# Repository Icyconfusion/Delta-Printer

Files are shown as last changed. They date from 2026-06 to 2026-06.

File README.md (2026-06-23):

# Delta Printer
An STM32 based delta style 3D printer running Marlin firmware. The printer features a custom PCB motherboard, LCD, and 220mm diameter x roughly 200mm build volume. I designed this project to expand on my understanding of 3D printer hardware and mechanics through non-standard motion.



**Note to reviewer:** My JLCPCB/MC screenshot is inclusive of tax and cheapest shipping option, it went into my "orders" tab despite not being paid for, but that is the total price, and the checkout page. Thank you:)

## Assembly
The key assembly ofthe printer is a triangular prism made of 2020 T slot aluminium profiles. Using 3d printed brackets, shorter T slots of lengths 340mm for the top and 290 for the bottom are arranged into triangles. 500mm T slot join these triangles. Two profiles are used for each tower to increase stiffness. The bottom bracket extends the height of the printer without needing extra T slot. Brackets are mounted using T nuts.




400mm MGN12H linear rails are mounted to the inside profile of each tower using M3x8 screws.



To mount the NEMA17 stepper motors, the motors are screwed into the mount bracket, which attaches to the inside of the two bottom triangles.





Bottom covers are added and the PCB is placed in the groove in the centre.




Idle pulleys are mounted to the top bracket with an M5 screw. The carriages are assembled with the ball joints screwed onto the carriage. M3 screws are threaded into the heat inserts and the GT2 belt is mounted. The carbon tube has an M3 stud glue into each end, which is threaded into the ball joint on each end.






### Effector Assembly
To assemble the effector, first mount the NEMA 17 stepper and filament gear.





Then mount the CR6-SE hotend into the heat inserts.



4010 fans mount on the back and side where they are ducted to the nozzle/part.




The extruder arm provides tension to the filament gear to ensure accurate and reliable extrusion of filament. The arm is spring loaded to push an 11x5x5 bearing, squeezing the filament against the drive gear. The arm pivots around the top left M3 NEMA 17 mounting screw. An M5 screw above this is threaded into the effector knob, and a spring in this spot provides tension. Finally, the ball joints are attached, and can be connected to the arms on the carriages.






To start closing the base compartment and installing the bed, the LCD must be installed. The LCD is screwed through the back into heat inserts in the LCD module printed part. This module is then mounted onto LCD base covers using heat inserts. This is then mounted onto the base using T nuts.









Base covers are mounted onto one of the other sides.



The third side holds the PSU. The PSU is held in its compartment, which is mounted to the frame in place. A base cover is mounted next to it. There is a hole in the base cover next to it for power cables to run from to PSU to the wall outlet.







Now the bed can be installed. To do this, printed bed supports are installed on the base. The bed then screws into these. If needed, depending on exact specifications of the bed, the holes to mount the bed can be made larger by printing or drilling.




To mount limit switches, the switches are screwed into heat inserts in the bracket, then mounted to the bottom of the towers. After this the printer is assembled.




## Electronics
The printer features a 2 layer PCB motherboard I designed around an STM32F407VGT6. TMC2209 drivers are used to control stepper motors, and subsequently motion. The board utilises mostly SMD components to minimise space and layer requirements. Power is brought onto the board using 7.62mm pitch screw terminals, which connect to the 24V 600w PSU. A buck converter and linear regulator convert this down to 5V and 3.3V logic levels. 5V is used only for the buck converter and the EXP1 header for the LCD. The LCD used it a BTT Mini 12864 V2.0, which interfaces with the PCB via EXP1 and EXP2 headers. The LCD also has an encoder, button and SD card reader. The heaters (hotend and bed if required in future) are controlled through TO-252-3 AOD4184 MOSFETs. Lower power mosfets, SOT-23 AO3400 MOSFETs, are used to control the 24V fans. There is a USB-C receptacle for firmware flashing, and an SWD header if needed. Most resistors and capacitors are size 0805, though there are exceptionswhere required. Because I am using the STM32, no external flash is required, as it is onboard.



Driver hierarchical sheet:



MOSFET hierarchical sheet:






Power:



EXP1 and EXP2:



The PCB is organised with drivers up the top. Power on the left edge, with the buck converter, regulator, power input terminal and fuse. MOSFETs are on the bottom, heaters on the right hand side. On the right edge, there is the USB-C receptacle, thermistors, endstops and LCD headers. The STM32 is situated in the center.





## Firmware
The firmware used is Marlin firmware. The firmware has been configured to match a delta printer with delta kinematics. Additionally, it has been configured for my custom motherboard by creating a unique pin mapping for the printer. The config and pin map files are in the firmware folder of the repo, along with the complete marlin .zip build folder.

## BOM
### Printed Parts

|Part| Quantity| Image|
|---|---|---|
|Bottom bracket | 3 |  |
|Top bracket | 3 |  |
|Bottom cover | 3 |  |
|Bed support | 3 |  |
|Motor mount | 3 |  |
|Carriage | 3 |  |
|PSU compartment | 3 |  |
|Base cover LCD | 2 |  |
|Base cover | 2 |  |
|Base cover PSU | 1 |  |
|LCD front cover | 1 |  |
|Extruder | 1 |  |
|Drive arm | 1 |  |
|Limit switch bracket | 3 |  |

### Parts already owned
| Part | Quantity | Description |
|--|--|--|
|T slot | 6 | 500mm 2020 T slot profiles |
|Linear rail | 3 | MGN12H 400mm linear rail and carriage |
|Motor | 4 | NEMA 17 stepper motor |
| Hotend | 1 | CR6 SE hotend |
| Fan | 2 | 4010 24v blower fan |
| GT2 bearing | 3 | 5mm bore gt2 idler bearing |
| GT2 gear | 3 | GT2 20T gear |
|LCD | 1 | BTT mini 12864 V2.0 LCD |
| Limit switch | 3 | Standard limit switch |
| T nut | - | M5 and M3 T nuts |
| PSU | 1 | 24V 600w PSU |

### Purchased parts
|Product |Quantity|Description |Total cost (USD)|Supplier  |Link |
|---|---|---|---|---|---|
|100nF Capacitors |26 |100nF 0805 ceramic capacitors for PCB |2.31 |Aliexpress|https://www.aliexpress.com/item/1005011894977575.html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 |
|100uF - Low ESR Cap|6 |50V 100uF Low ESR caps in 6.3x7.7 package. Used for Vm on TMC2209 |3.69 |Aliexpress|https://www.aliexpress.com/item/1005006846973435.html |
|2.2uF cap |6 |0805 2.2uF 50V ceramic capacitors |2.2 |Aliexpress|https://www.aliexpress.com/item/1005007293718666.html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 |
|22nF cap |4 |0805 22nF 50V ca- |2.2 |Aliexpress|https://www.aliexpress.com/item/1005011894977575.html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 |
|1uF cap |4 |0805 1uF 50V capacitor |2.04 |Aliexpress|https://www.aliexpress.com/item/1005007293718666.html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 |
|18pF cap |2 |0805 18pF cap for crystal |2.52 |Aliexpress|https://www.aliexpress.com/item/1005002958706092.html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 |
|22uF cap |4 |0805 22uF 50V capacitor |2.86 |Aliexpress|https://www.aliexpress.com/item/1005007293718666.html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 |
|10uF cap |6 |0805 10uF cap |2.54 |Aliexpress|https://www.aliexpress.com/item/1005007293718666.html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 |
|220pF cap |1 |0805 220pF 50V cap |4.04 |Aliexpress|https://www.aliexpress.com/item/1005011884524334.html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 |
|SS34 diode |1 |SS34 SMA Schottky diode |2.89 |Aliexpress|https://www.aliexpress.com/item/1005003929814084.html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 |
|Ferrite bead |1 |0805 600R 100mhz ferrite bead |3.93 |Aliexpress|https://www.aliexpress.com/item/1005003127666910.html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 |
|IDC header |2 |2x5 pin 2.54mm IDC header for EXP1/2 |4.77 |Aliexpress|https://www.aliexpress.com/item/32658384492.html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 |
|JST-XH header |7 |JST-XH 2.54mm header for conencting heaters and fans |1.83 |Aliexpress|https://www.aliexpress.com/item/1005004985397880.html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 |
|10uH inductor |1 |6x6x3 10uH inductor |3.5 |Aliexpress|https://www.aliexpress.com/item/1005006817003873.html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 |
|MOSFET |2 |TO252-3 AOD4184 SMD MOSFET for heaters |3.7 |Aliexpress|https://www.aliexpress.com/item/1005006044488568.html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 |
|Fan MOSFET |3 |SOT-23 AO3400 SMD MOSFET |1.87 |Aliexpress|https://www.aliexpress.com/item/1005006286601118.html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 |
|Resistor 0.5W |8 |1206 0.5W 0.15 ohm sense resistor for TMC 2209 |1.62 |Aliexpress|https://www.aliexpress.com/item/1005005905538731.html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 |
|1K resistor |5 |0805 1k ohm resistor |2.48 |Aliexpress|https://www.aliexpress.com/item/32936483115.html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 |
|10k resistor |12 |0805 10k resistor |2.53 |Aliexpress|https://www.aliexpress.com/item/32936483115.html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 |
|100 resistor |6 |100 ohm 0805 resistor |2.44 |Aliexpress|https://www.aliexpress.com/item/32936483115.html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 |
|5.1K resistor |2 |0805 5.1k resistor |2.48 |Aliexpress|https://www.aliexpress.com/item/32936483115.html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 |
|33 resistor |2 |0805 33 ohm resistor |2.44 |Aliexpress|https://www.aliexpress.com/item/32936483115.html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 |
|52.3K resistor |1 |0805 52.3k resistor |1.8 |Aliexpress|https://www.aliexpress.com/item/1005005184354247.html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 |
|100k resistor |1 |0805 100k resistor |3.04 |Aliexpress|https://www.aliexpress.com/item/1005007183002569.html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 |
|24.9K resistor |1 |0805 24.9k resistor |1.72 |Aliexpress|https://www.aliexpress.com/item/1005005184354288.html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 |
|68.1K resistor |1 |0805 68.1k resistor |1.72 |Aliexpress|https://www.aliexpress.com/item/1005005187548543.html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 |
|22 resistor |2 |0805 22 ohm resistor |2.59 |Aliexpress|https://www.aliexpress.com/item/32936483115.html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 |
|Pushbutton |1 |TS-1088-AR02016 pushbutton |1.09 |Aliexpress|https://www.aliexpress.com/item/1005011940516004.html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 |
|STM32 |1 |STM32F407VGT6 MCU |4.58 |Aliexpress|https://www.aliexpress.com/item/1005006367005179.html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 |
|TMC2209-LA |4 |TMC 2209 stepper driver |7.12 |Aliexpress|https://www.aliexpress.com/item/1005009186342077.html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 |
|MP1584-EN |1 |Buck converter for 24V to 5V |3.23 |Aliexpress|https://www.aliexpress.com/item/1005007296268441.html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 |
|AP-2112K-3.3 |1 |Linear regulator for 5V to 3.3V |2.43 |Aliexpress|https://www.aliexpress.com/item/1005009023441155.html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 |
|Crystal |1 |8mhz 3225 SMD crystal, 4 pad |3 |Aliexpress|https://www.aliexpress.com/item/1005005834614422.html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 |
|Bed |1 |220mm diameter kossel delta 3d print bed |18.8 |Aliexpress|https://www.aliexpress.com/item/33042838050.html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 |
|Carbon tube |2 |500mm lengths of 8x6 carbon fibre tube. Comes in packs of two, I will need two packs, and cut each rod into two 230mm lengths|14 |Aliexpress|https://www.aliexpress.com/item/1005006133534969.html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 |
|Ball joints |12 |M3 26mm ball joints for the arms |11 |Aliexpress|https://www.aliexpress.com/item/1005006781375729.html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 |
|GT2 belt |1 |5M GT2 6mm belt for moving the carriages |4.3 |Aliexpress|https://www.aliexpress.com/item/1005008378063451.html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 |
|Filament drive gear|1 |Filament drive gear to extrude filament |2.18 |Aliexpress|https://www.aliexpress.com/item/32296703817.html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 |
|Bearing |1 |11x5x5 bearing for idler arm |0.11 |JLCMC |https://jlcmc.com/product/b/C15/BR8364/deep-groove-ball-bearing-double-side-with-dust-cover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 |
|M5x16 |2 |SCM435 screw for assembly |0.04 |JLCMC |https://jlcmc.com/product/s/E02/EDLA/din-912-gb-t-70.1-standard-socket-head-cap-screws-full---half-thread |
|M5x22 |1 |SCM435 screw for assembly |0.02 |JLCMC |https://jlcmc.com/product/s/E02/EDLA/din-912-gb-t-70.1-standard-socket-head-cap-screws-full---half-thread |
|M5x10 |75 |SCM435 screw for assembly |1.18 |JLCMC |https://jlcmc.com/product/s/E02/EDLA/din-912-gb-t-70.1-standard-socket-head-cap-screws-full---half-thread |
|M3x8 |48 |SCM435 screw for assembly |0.56 |JLCMC |https://jlcmc.com/product/s/E02/EDLA/din-912-gb-t-70.1-standard-socket-head-cap-screws-full---half-thread |
|M3x10 |31 |SCM435 screw for assembly |0.25 |JLCMC |https://jlcmc.com/product/s/E02/EDLA/din-912-gb-t-70.1-standard-socket-head-cap-screws-full---half-thread |
|340mm T slot |3 |340mm 2020 T slot |2.63 |JLCMC |https://jlcmc.com/product/s/T01/TXCJ/extruded-aluminum-t-slot-20-series(eu) |
|290mm T slot |6 |290mm 2020 T slot for the base triangles |4.8 |JLCMC |https://jlcmc.com/product/s/T01/TXCJ/extruded-aluminum-t-slot-20-series(eu) |
|M3 heat insert |4 |M3 OD4 L5-6mm |2.53 |Aliexpress|https://www.aliexpress.com/item/1005008897571758.html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|
|M2 heat insert |6 |M2 OD3.2 L6 |2.42 |Aliexpress|https://www.aliexpress.com/item/1005008666672949.html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 |
|M5 heat insert |3 |M5 OD7.1 L6 |2.61 |Aliexpress|https://www.aliexpress.com/item/1005008666672949.html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 |
|M2.5 Heat insert |8 |M2.5 OD3.5 L6 |2.47 |Aliexpress|https://www.aliexpress.com/item/1005008897571758.html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|
|PCB |1 |PCB |8.89 |JLCPCB |https://jlcmc.com/product/s/E02/EDLA/din-912-gb-t-70.1-standard-socket-head-cap-screws-full---half-thread |

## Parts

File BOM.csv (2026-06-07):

Product | Quantity | Description | Total cost (USD) | Supplier | Link
100nF Capacitors | 26 | 100nF 0805 ceramic capacitors for PCB | 2.31 | Aliexpress | https://www.aliexpress.com/item/1005011894977575.html?curPageLogUid=lO0BHaX0NqCM
100uF - Low ESR Cap | 6 | 50V 100uF Low ESR caps in 6.3x7.7 package. Used for Vm on TMC2209 | 3.69 | Aliexpress | https://www.aliexpress.com/item/1005006846973435.html
2.2uF cap | 6 | 0805 2.2uF 50V ceramic capacitors | 2.2 | Aliexpress | https://www.aliexpress.com/item/1005007293718666.html?curPageLogUid=OS4dkcks5GAl
22nF cap | 4 | 0805 22nF 50V ca- | 2.2 | Aliexpress | https://www.aliexpress.com/item/1005011894977575.html?curPageLogUid=lO0BHaX0NqCM
1uF cap | 4 | 0805 1uF 50V capacitor | 2.04 | Aliexpress | https://www.aliexpress.com/item/1005007293718666.html?curPageLogUid=OS4dkcks5GAl
18pF cap | 2 | 0805 18pF cap for crystal | 2.52 | Aliexpress | https://www.aliexpress.com/item/1005002958706092.html?curPageLogUid=HO0lalvIulA4
22uF cap | 4 | 0805 22uF 50V capacitor | 2.86 | Aliexpress | https://www.aliexpress.com/item/1005007293718666.html?curPageLogUid=OS4dkcks5GAl
10uF cap | 6 | 0805 10uF cap | 2.54 | Aliexpress | https://www.aliexpress.com/item/1005007293718666.html?curPageLogUid=OS4dkcks5GAl
220pF cap | 1 | 0805 220pF 50V cap | 4.04 | Aliexpress | https://www.aliexpress.com/item/1005011884524334.html?curPageLogUid=1xTiDLuHV5Su
SS34 diode | 1 | SS34 SMA Schottky diode | 2.89 | Aliexpress | https://www.aliexpress.com/item/1005003929814084.html?curPageLogUid=NnPur3r1YfyF
Ferrite bead | 1 | 0805 600R 100mhz ferrite bead | 3.93 | Aliexpress | https://www.aliexpress.com/item/1005003127666910.html?curPageLogUid=ES5AkXMpY2mV
IDC header | 2 | 2x5 pin 2.54mm IDC header for EXP1/2 | 4.77 | Aliexpress | https://www.aliexpress.com/item/32658384492.html?curPageLogUid=g4IB6NhYXd4C
JST-XH header | 7 | JST-XH 2.54mm header for conencting heaters and fans | 1.83 | Aliexpress | https://www.aliexpress.com/item/1005004985397880.html?curPageLogUid=7n7ud5jLy3vZ
10uH inductor | 1 | 6x6x3 10uH inductor | 3.5 | Aliexpress | https://www.aliexpress.com/item/1005006817003873.html?curPageLogUid=Uw0smIdCVuNn
MOSFET | 2 | TO252-3 AOD4184 SMD MOSFET for heaters | 3.7 | Aliexpress | https://www.aliexpress.com/item/1005006044488568.html?curPageLogUid=S5OfV9YlN4WJ
Fan MOSFET | 3 | SOT-23 AO3400 SMD MOSFET | 1.87 | Aliexpress | https://www.aliexpress.com/item/1005006286601118.html?curPageLogUid=dHrfVQrllnN6
Resistor 0.5W | 8 | 1206 0.5W 0.15 ohm sense resistor for TMC 2209 | 1.62 | Aliexpress | https://www.aliexpress.com/item/1005005905538731.html?curPageLogUid=Pfo42AofQ8rk
1K resistor | 5 | 0805 1k ohm resistor | 2.48 | Aliexpress | https://www.aliexpress.com/item/32936483115.html?curPageLogUid=dNfs5t7vpWyj
10k resistor | 12 | 0805 10k resistor | 2.53 | Aliexpress | https://www.aliexpress.com/item/32936483115.html?curPageLogUid=dNfs5t7vpWyj
100 resistor | 6 | 100 ohm 0805 resistor | 2.44 | Aliexpress | https://www.aliexpress.com/item/32936483115.html?curPageLogUid=dNfs5t7vpWyj
5.1K resistor | 2 | 0805 5.1k resistor | 2.48 | Aliexpress | https://www.aliexpress.com/item/32936483115.html?curPageLogUid=dNfs5t7vpWyj
33 resistor | 2 | 0805 33 ohm resistor | 2.44 | Aliexpress | https://www.aliexpress.com/item/32936483115.html?curPageLogUid=dNfs5t7vpWyj
52.3K resistor | 1 | 0805 52.3k resistor | 1.8 | Aliexpress | https://www.aliexpress.com/item/1005005184354247.html?curPageLogUid=rQRCWdSXORAa
100k resistor | 1 | 0805 100k resistor | 3.04 | Aliexpress | https://www.aliexpress.com/item/1005007183002569.html?curPageLogUid=CMCONd03B1Mp
24.9K resistor | 1 | 0805 24.9k resistor | 1.72 | Aliexpress | https://www.aliexpress.com/item/1005005184354288.html?curPageLogUid=G58tsGOWqItU
68.1K resistor | 1 | 0805 68.1k resistor | 1.72 | Aliexpress | https://www.aliexpress.com/item/1005005187548543.html?curPageLogUid=MXuPuWllAnmZ
22 resistor | 2 | 0805 22 ohm resistor | 2.59 | Aliexpress | https://www.aliexpress.com/item/32936483115.html?curPageLogUid=dNfs5t7vpWyj
Pushbutton | 1 | TS-1088-AR02016 pushbutton | 1.09 | Aliexpress | https://www.aliexpress.com/item/1005011940516004.html?curPageLogUid=CfBxlh486V12
STM32 | 1 | STM32F407VGT6 MCU | 4.58 | Aliexpress | https://www.aliexpress.com/item/1005006367005179.html?curPageLogUid=dqBBw4AoHYAD
TMC2209-LA | 4 | TMC 2209 stepper driver | 7.12 | Aliexpress | https://www.aliexpress.com/item/1005009186342077.html?curPageLogUid=HlIqvvGecP1u
MP1584-EN | 1 | Buck converter for 24V to 5V | 3.23 | Aliexpress | https://www.aliexpress.com/item/1005007296268441.html?curPageLogUid=A34AWEWBjMRx
AP-2112K-3.3 | 1 | Linear regulator for 5V to 3.3V | 2.43 | Aliexpress | https://www.aliexpress.com/item/1005009023441155.html?curPageLogUid=zwSUqLx0jcxh
Crystal | 1 | 8mhz 3225 SMD crystal, 4 pad | 3 | Aliexpress | https://www.aliexpress.com/item/1005005834614422.html?curPageLogUid=t2KRH5g72Zws
Bed | 1 | 220mm diameter kossel delta 3d print bed | 18.8 | Aliexpress | https://www.aliexpress.com/item/33042838050.html?mp=1
Carbon tube | 2 | 500mm lengths of 8x6 carbon fibre tube. Comes in packs of two, I will need two packs, and cut each rod into two 230mm lengths | 14 | Aliexpress | https://www.aliexpress.com/item/1005006133534969.html?mp=1
Ball joints | 12 | M3 26mm ball joints for the arms | 11 | Aliexpress | https://www.aliexpress.com/item/1005006781375729.html?curPageLogUid=FTtu6kDYbUIQ
GT2 belt | 1 | 5M GT2 6mm belt for moving the carriages | 4.3 | Aliexpress | https://www.aliexpress.com/item/1005008378063451.html?curPageLogUid=wyaNDkXzWcC4
Filament drive gear | 1 | Filament drive gear to extrude filament | 2.18 | Aliexpress | https://www.aliexpress.com/item/32296703817.html?curPageLogUid=DQ9u4zyL0oho
Bearing | 1 | 11x5x5 bearing for idler arm | 0.11 | JLCMC | https://jlcmc.com/product/b/C15/BR8364/deep-groove-ball-bearing-double-side-with-dust-cover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
M5x16 | 2 | SCM435 screw for assembly | 0.04 | JLCMC | https://jlcmc.com/product/s/E02/EDLA/din-912-gb-t-70.1-standard-socket-head-cap-screws-full---half-thread
M5x22 | 1 | SCM435 screw for assembly | 0.02 | JLCMC | https://jlcmc.com/product/s/E02/EDLA/din-912-gb-t-70.1-standard-socket-head-cap-screws-full---half-thread
M5x10 | 75 | SCM435 screw for assembly | 1.18 | JLCMC | https://jlcmc.com/product/s/E02/EDLA/din-912-gb-t-70.1-standard-socket-head-cap-screws-full---half-thread
M3x8 | 48 | SCM435 screw for assembly | 0.56 | JLCMC | https://jlcmc.com/product/s/E02/EDLA/din-912-gb-t-70.1-standard-socket-head-cap-screws-full---half-thread
M3x10 | 31 | SCM435 screw for assembly | 0.25 | JLCMC | https://jlcmc.com/product/s/E02/EDLA/din-912-gb-t-70.1-standard-socket-head-cap-screws-full---half-thread
340mm T slot | 3 | 340mm 2020 T slot | 2.63 | JLCMC | https://jlcmc.com/product/s/T01/TXCJ/extruded-aluminum-t-slot-20-series(eu)
290mm T slot | 6 | 290mm 2020 T slot for the base triangles | 4.8 | JLCMC | https://jlcmc.com/product/s/T01/TXCJ/extruded-aluminum-t-slot-20-series(eu)
M3 heat insert | 4 | M3 OD4 L5-6mm | 2.53 | Aliexpress | https://www.aliexpress.com/item/1005008897571758.html?curPageLogUid=nP77GEie3UaZ
M2 heat insert | 6 | M2 OD3.2 L6 | 2.42 | Aliexpress | https://www.aliexpress.com/item/1005008666672949.html?curPageLogUid=lO13mEhcc5fv
M5 heat insert | 3 | M5 OD7.1 L6 | 2.61 | Aliexpress | https://www.aliexpress.com/item/1005008666672949.html?curPageLogUid=lO13mEhcc5fv
M2.5 Heat insert | 8 | M2.5 OD3.5 L6 | 2.47 | Aliexpress | https://www.aliexpress.com/item/1005008897571758.html?curPageLogUid=nP77GEie3UaZ
PCB | 1 | PCB | 8.89 | JLCPCB | https://jlcmc.com/product/s/E02/EDLA/din-912-gb-t-70.1-standard-socket-head-cap-screws-full---half-thread

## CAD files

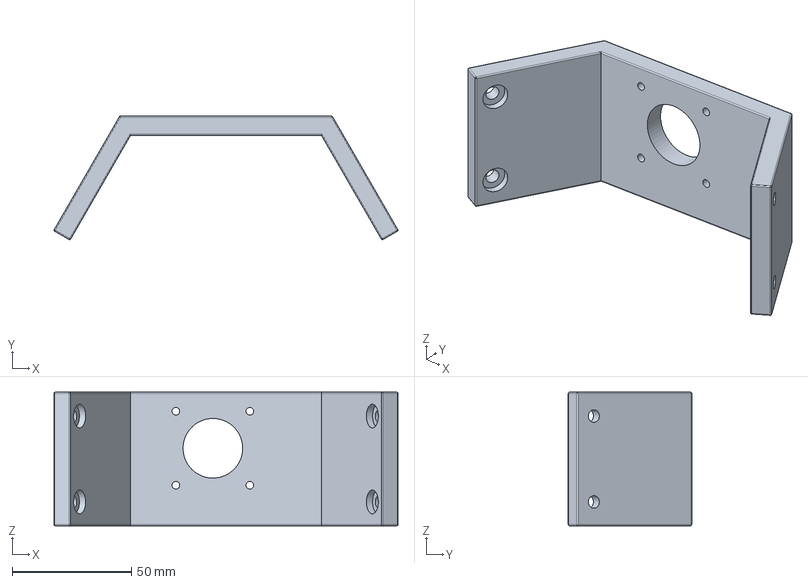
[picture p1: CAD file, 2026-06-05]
CAD/New motor mount.step
144.2 x 51.8 x 56.0 mm

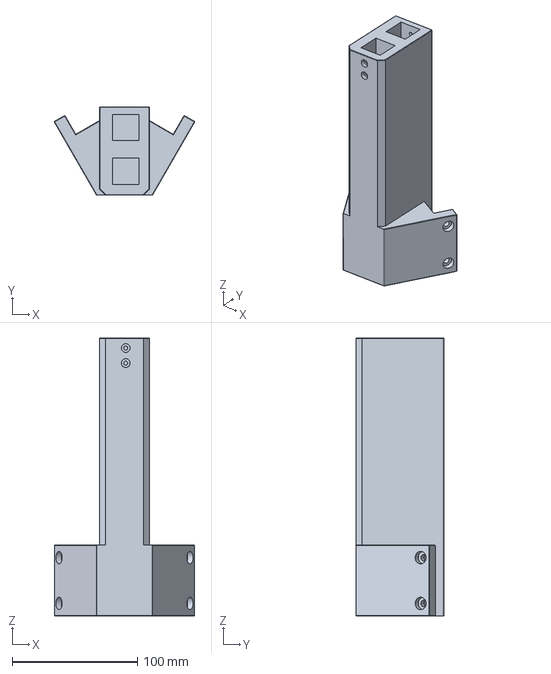
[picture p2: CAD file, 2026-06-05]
CAD/Bottom bracket.step
112.0 x 70.5 x 221.5 mm

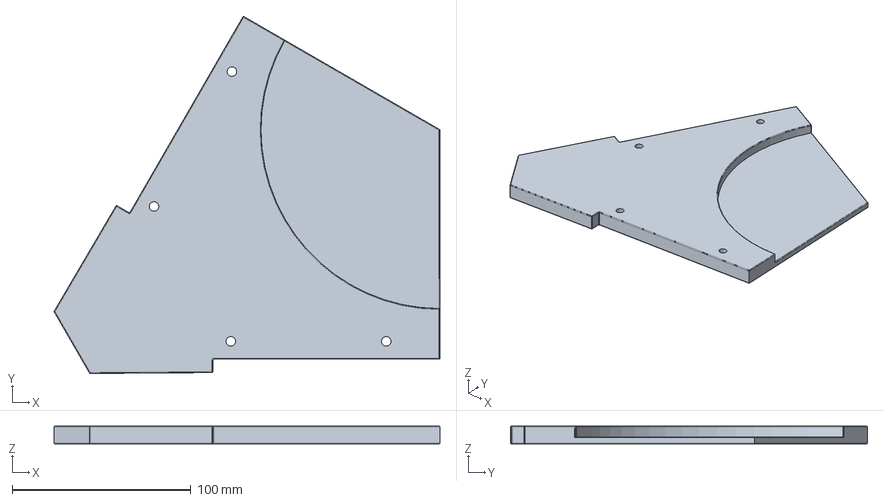
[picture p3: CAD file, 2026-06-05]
CAD/Bottom cover.step
215.7 x 199.6 x 10.0 mm

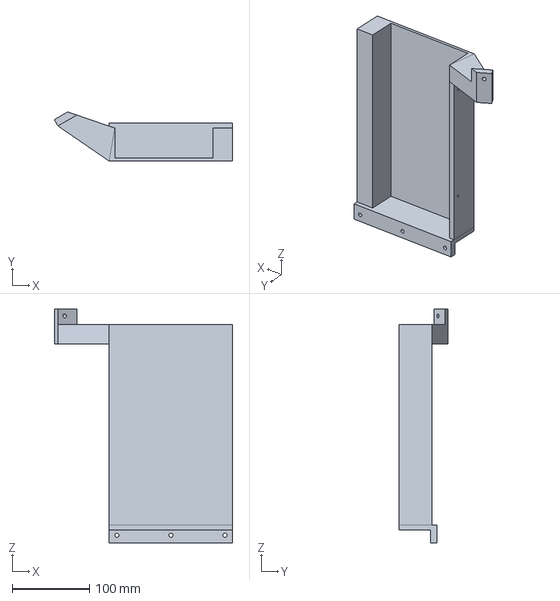
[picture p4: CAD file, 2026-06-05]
CAD/PSU Compartment.step
231.0 x 63.7 x 302.9 mm

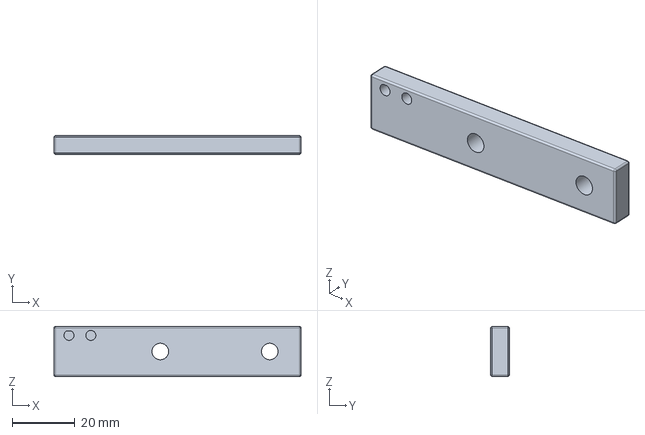
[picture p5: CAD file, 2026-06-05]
CAD/Limit switch bracket.step
79.0 x 6.00 x 16.0 mm

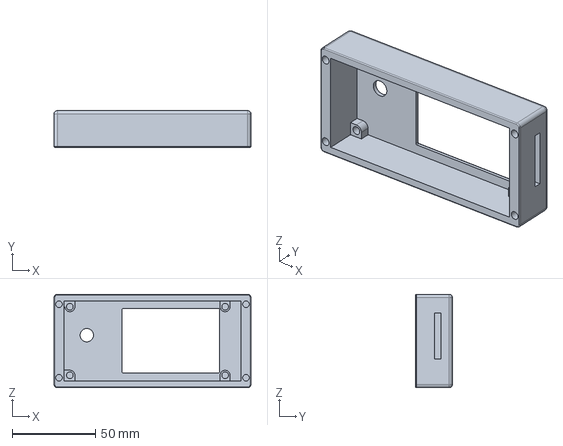
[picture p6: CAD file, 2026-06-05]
CAD/LCD front cover.step
118.0 x 22.0 x 56.0 mm

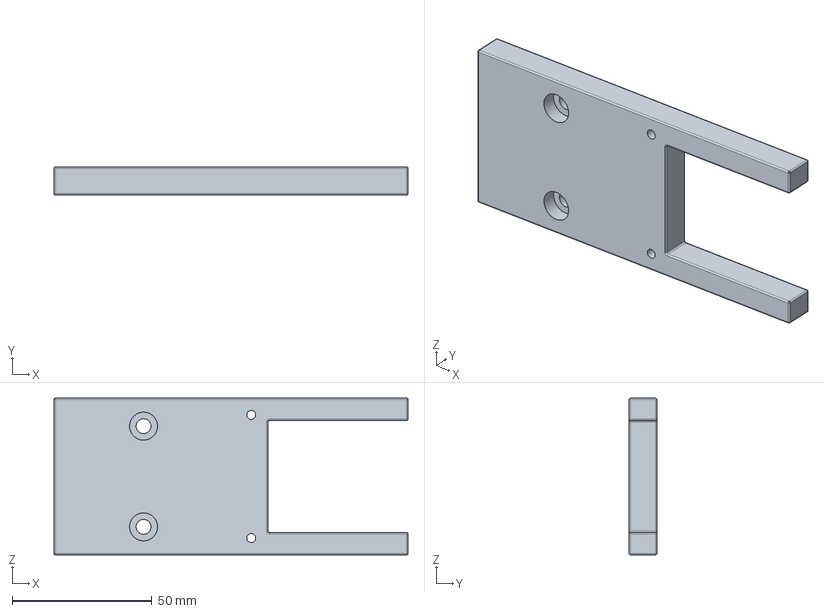
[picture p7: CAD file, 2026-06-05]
CAD/Base cover LCD_.step
126.5 x 10.0 x 56.0 mm

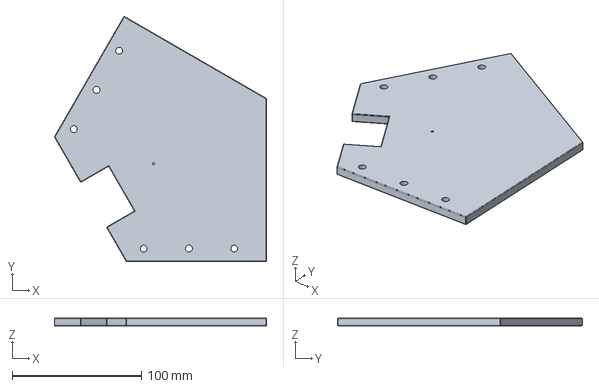
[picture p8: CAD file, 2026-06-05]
CAD/Bed support.step
164.0 x 189.5 x 6.00 mm

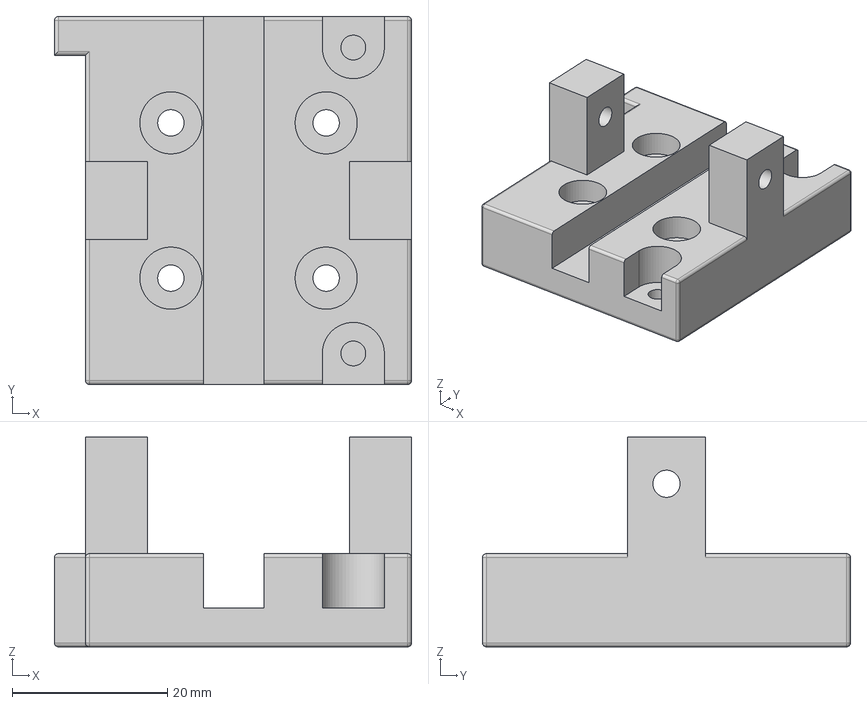
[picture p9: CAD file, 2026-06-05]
CAD/Carriage.step
46.0 x 47.4 x 27.0 mm

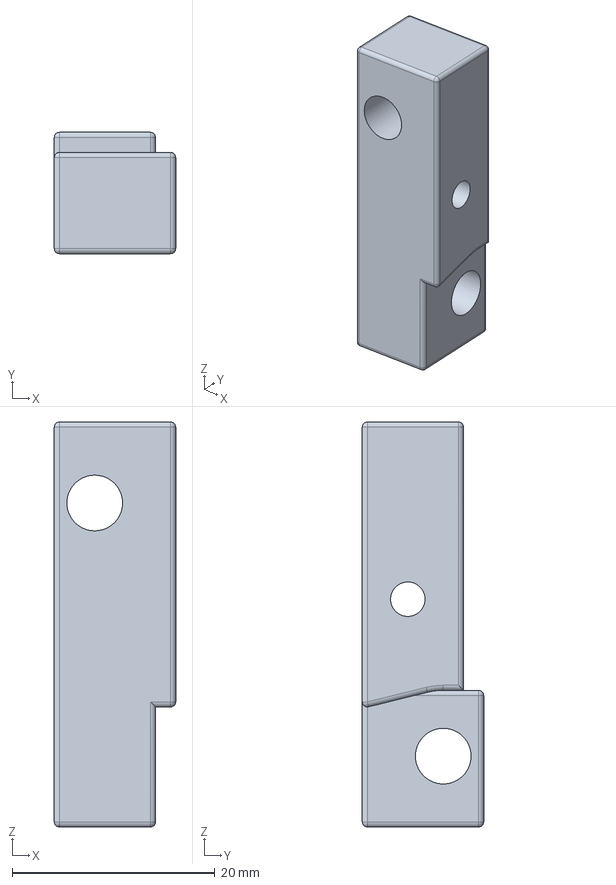
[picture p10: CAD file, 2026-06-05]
CAD/Drive arm.step
12.0 x 12.0 x 40.0 mm

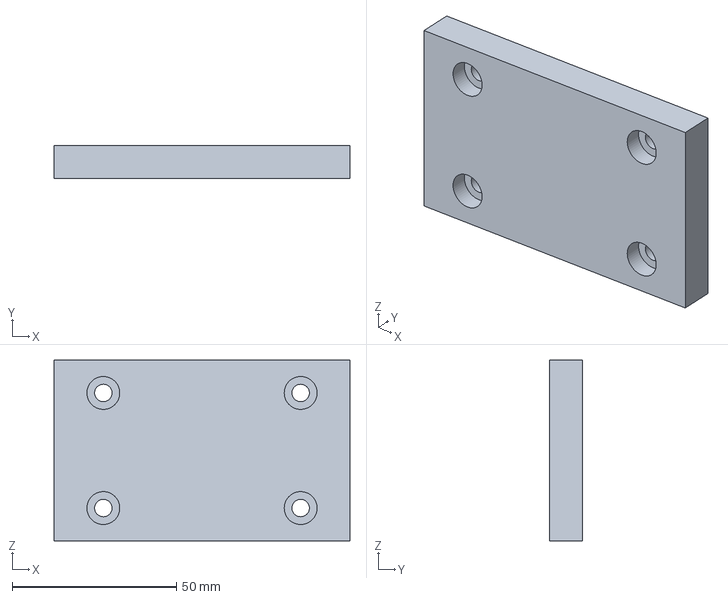
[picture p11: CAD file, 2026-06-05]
CAD/PSU base cover.step
90.0 x 10.0 x 55.0 mm

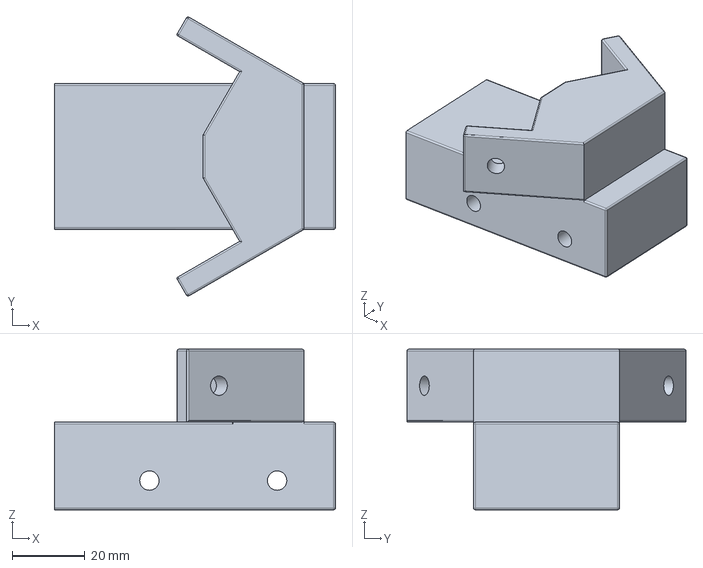
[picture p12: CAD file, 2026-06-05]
CAD/Top bracket.step
77.0 x 76.5 x 44.0 mm

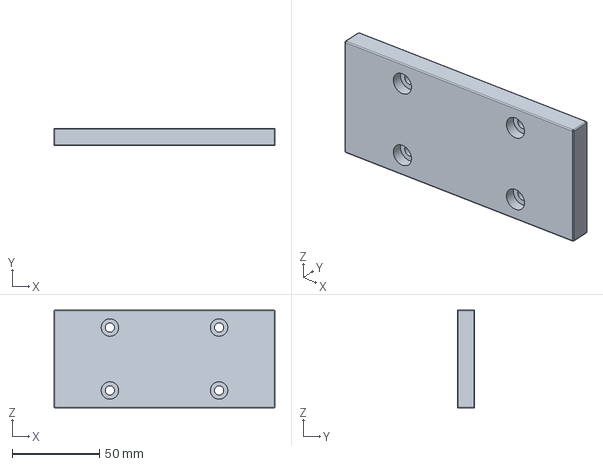
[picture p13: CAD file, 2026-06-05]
CAD/Base cover.step
126.5 x 10.0 x 56.0 mm

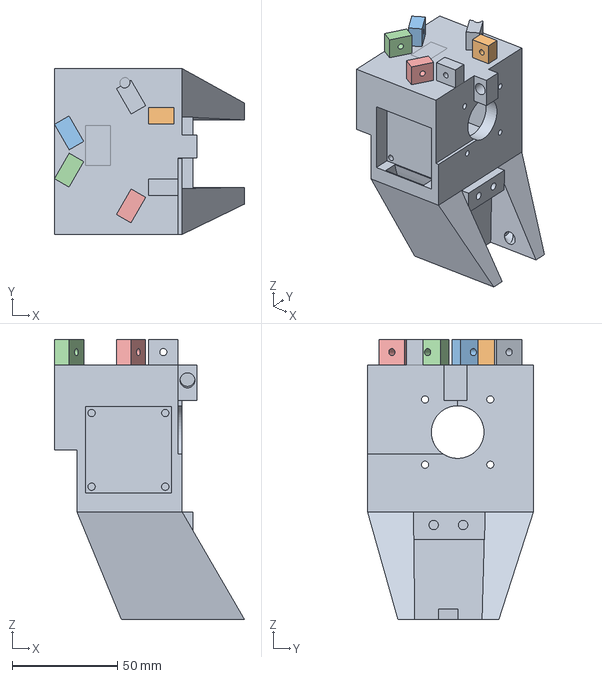
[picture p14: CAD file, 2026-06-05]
CAD/Extruder.step
90.3 x 78.8 x 133.1 mm

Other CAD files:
Assembly/Assembly.stp

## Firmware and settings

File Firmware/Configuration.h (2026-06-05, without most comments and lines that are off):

#pragma once
#define CONFIGURATION_H_VERSION 02010206
#define STRING_CONFIG_H_AUTHOR "(none, default config)" // Who made the changes.
#define SHOW_BOOTSCREEN
  #define MOTHERBOARD BOARD_DELTA
#define SERIAL_PORT 0
#define BAUDRATE 250000
#define X_DRIVER_TYPE  TMC2209
#define Y_DRIVER_TYPE  TMC2209
#define Z_DRIVER_TYPE  TMC2209
#define E0_DRIVER_TYPE TMC2209
#define EXTRUDERS 1
#define DEFAULT_NOMINAL_FILAMENT_DIA 1.75
#define TEMP_SENSOR_0 1
#define TEMP_SENSOR_1 0
#define TEMP_SENSOR_2 0
#define TEMP_SENSOR_3 0
#define TEMP_SENSOR_4 0
#define TEMP_SENSOR_5 0
#define TEMP_SENSOR_6 0
#define TEMP_SENSOR_7 0
#define TEMP_SENSOR_BED 1
#define TEMP_SENSOR_PROBE 0
#define TEMP_SENSOR_CHAMBER 0
#define TEMP_SENSOR_COOLER 0
#define TEMP_SENSOR_BOARD 0
#define TEMP_SENSOR_REDUNDANT 0
#define DUMMY_THERMISTOR_998_VALUE  25
#define DUMMY_THERMISTOR_999_VALUE 100
#if TEMP_SENSOR_IS_MAX_TC(0)
  #define MAX31865_SENSOR_OHMS_0      100 // (Ω) Typically 100 or 1000 (PT100 or PT1000)
  #define MAX31865_CALIBRATION_OHMS_0 430 // (Ω) Typically 430 for Adafruit PT100; 4300 for Adafruit PT1000
#endif
#if TEMP_SENSOR_IS_MAX_TC(1)
  #define MAX31865_SENSOR_OHMS_1      100
  #define MAX31865_CALIBRATION_OHMS_1 430
#endif
#if TEMP_SENSOR_IS_MAX_TC(2)
  #define MAX31865_SENSOR_OHMS_2      100
  #define MAX31865_CALIBRATION_OHMS_2 430
#endif
#if HAS_E_TEMP_SENSOR
  #define TEMP_RESIDENCY_TIME         10  // (seconds) Time to wait for hotend to "settle" in M109
  #define TEMP_WINDOW                  1  // (°C) Temperature proximity for the "temperature reached" timer
  #define TEMP_HYSTERESIS              3  // (°C) Temperature proximity considered "close enough" to the target
#endif
#if TEMP_SENSOR_BED
  #define TEMP_BED_RESIDENCY_TIME     10  // (seconds) Time to wait for bed to "settle" in M190
  #define TEMP_BED_WINDOW              1  // (°C) Temperature proximity for the "temperature reached" timer
  #define TEMP_BED_HYSTERESIS          3  // (°C) Temperature proximity considered "close enough" to the target
#endif
#if TEMP_SENSOR_CHAMBER
  #define TEMP_CHAMBER_RESIDENCY_TIME 10  // (seconds) Time to wait for chamber to "settle" in M191
  #define TEMP_CHAMBER_WINDOW          1  // (°C) Temperature proximity for the "temperature reached" timer
  #define TEMP_CHAMBER_HYSTERESIS      3  // (°C) Temperature proximity considered "close enough" to the target
#endif
#if TEMP_SENSOR_REDUNDANT
  #define TEMP_SENSOR_REDUNDANT_SOURCE    E1  // The sensor that will provide the redundant reading.
  #define TEMP_SENSOR_REDUNDANT_TARGET    E0  // The sensor that we are providing a redundant reading for.
  #define TEMP_SENSOR_REDUNDANT_MAX_DIFF  10  // (°C) Temperature difference that will trigger a print abort.
#endif
#define HEATER_0_MINTEMP   5
#define HEATER_1_MINTEMP   5
#define HEATER_2_MINTEMP   5
#define HEATER_3_MINTEMP   5
#define HEATER_4_MINTEMP   5
#define HEATER_5_MINTEMP   5
#define HEATER_6_MINTEMP   5
#define HEATER_7_MINTEMP   5
#define BED_MINTEMP        5
#define CHAMBER_MINTEMP    5
#define HEATER_0_MAXTEMP 290
#define HEATER_1_MAXTEMP 275
#define HEATER_2_MAXTEMP 275
#define HEATER_3_MAXTEMP 275
#define HEATER_4_MAXTEMP 275
#define HEATER_5_MAXTEMP 275
#define HEATER_6_MAXTEMP 275
#define HEATER_7_MAXTEMP 275
#define BED_MAXTEMP      150
#define CHAMBER_MAXTEMP  60
#define HOTEND_OVERSHOOT 15   // (°C) Forbid temperatures over MAXTEMP - OVERSHOOT
#define BED_OVERSHOOT    10   // (°C) Forbid temperatures over MAXTEMP - OVERSHOOT
#define COOLER_OVERSHOOT  2   // (°C) Forbid temperatures closer than OVERSHOOT
#define PIDTEMP           // See the PID Tuning Guide at https://reprap.org/wiki/PID_Tuning
#define PID_MAX  255      // Limit hotend current while PID is active (see PID_FUNCTIONAL_RANGE below); 255=full current
#define PID_K1     0.95   // Smoothing factor within any PID loop
    #define DEFAULT_KP  22.20
    #define DEFAULT_KI   1.08
    #define DEFAULT_KD 114.00
#define MAX_BED_POWER 255 // limits duty cycle to bed; 255=full current
#define MAX_CHAMBER_POWER 255 // limits duty cycle to chamber heater; 255=full current
  #define PID_FUNCTIONAL_RANGE 10 // If the temperature difference between the target temperature and the actual temperature
#define PREVENT_COLD_EXTRUSION
#define EXTRUDE_MINTEMP 170
#define PREVENT_LENGTHY_EXTRUDE
#define EXTRUDE_MAXLENGTH 200
#define THERMAL_PROTECTION_HOTENDS // Enable thermal protection for all extruders
#define THERMAL_PROTECTION_BED     // Enable thermal protection for the heated bed
#define THERMAL_PROTECTION_CHAMBER // Enable thermal protection for the heated chamber
#define THERMAL_PROTECTION_COOLER  // Enable thermal protection for the laser cooling
#define DELTA
  #define DEFAULT_SEGMENTS_PER_SECOND 200
  #define DELTA_CALIBRATION_MENU
    #define PROBE_MANUALLY_STEP 0.05      // (mm)
  #define DELTA_PRINTABLE_RADIUS 100.0    // (mm)
  #define DELTA_MAX_RADIUS       130.0    // (mm)
  #define DELTA_DIAGONAL_ROD 272.5        // (mm)
  #define DELTA_HEIGHT 100.00             // (mm) Get this value from G33 auto calibrate
  #define DELTA_ENDSTOP_ADJ { 0.0, 0.0, 0.0 } // (mm) Get these values from G33 auto calibrate
  #define DELTA_RADIUS 117.0              // (mm) Get this value from G33 auto calibrate
  #define DELTA_TOWER_ANGLE_TRIM { 0.0, 0.0, 0.0 } // (mm) Get these values from G33 auto calibrate
#define USE_XMIN_PLUG
#define USE_YMIN_PLUG
#define USE_ZMIN_PLUG
#define ENDSTOPPULLUPS
#define X_MIN_ENDSTOP_INVERTING false // Set to true to invert the logic of the endstop.
#define Y_MIN_ENDSTOP_INVERTING false // Set to true to invert the logic of the endstop.
#define Z_MIN_ENDSTOP_INVERTING false // Set to true to invert the logic of the endstop.
#define I_MIN_ENDSTOP_INVERTING false // Set to true to invert the logic of the endstop.
#define J_MIN_ENDSTOP_INVERTING false // Set to true to invert the logic of the endstop.
#define K_MIN_ENDSTOP_INVERTING false // Set to true to invert the logic of the endstop.
#define U_MIN_ENDSTOP_INVERTING false // Set to true to invert the logic of the endstop.
#define V_MIN_ENDSTOP_INVERTING false // Set to true to invert the logic of the endstop.
#define W_MIN_ENDSTOP_INVERTING false // Set to true to invert the logic of the endstop.
#define X_MAX_ENDSTOP_INVERTING false // Set to true to invert the logic of the endstop.
#define Y_MAX_ENDSTOP_INVERTING false // Set to true to invert the logic of the endstop.
#define Z_MAX_ENDSTOP_INVERTING false // Set to true to invert the logic of the endstop.
#define I_MAX_ENDSTOP_INVERTING false // Set to true to invert the logic of the endstop.
#define J_MAX_ENDSTOP_INVERTING false // Set to true to invert the logic of the endstop.
#define K_MAX_ENDSTOP_INVERTING false // Set to true to invert the logic of the endstop.
#define U_MAX_ENDSTOP_INVERTING false // Set to true to invert the logic of the endstop.
#define V_MAX_ENDSTOP_INVERTING false // Set to true to invert the logic of the endstop.
#define W_MAX_ENDSTOP_INVERTING false // Set to true to invert the logic of the endstop.
#define Z_MIN_PROBE_ENDSTOP_INVERTING false // Set to true to invert the logic of the probe.
#define DEFAULT_AXIS_STEPS_PER_UNIT   { 80, 80, 80, 500 }
#define DEFAULT_MAX_FEEDRATE          { 300, 300, 300, 25 }
#define DEFAULT_MAX_ACCELERATION      { 3000, 3000, 3000, 10000 }
#define DEFAULT_ACCELERATION          3000    // X, Y, Z and E acceleration for printing moves
#define DEFAULT_RETRACT_ACCELERATION  3000    // E acceleration for retracts
#define DEFAULT_TRAVEL_ACCELERATION   3000    // X, Y, Z acceleration for travel (non printing) moves
#define DEFAULT_EJERK    5.0  // May be used by Linear Advance
  #define JUNCTION_DEVIATION_MM 0.013 // (mm) Distance from real junction edge
  #define JD_HANDLE_SMALL_SEGMENTS    // Use curvature estimation instead of just the junction angle
#define Z_MIN_PROBE_USES_Z_MIN_ENDSTOP_PIN
#define PROBE_MANUALLY
#define NOZZLE_TO_PROBE_OFFSET { 10, 10, 0 }
#define PROBING_MARGIN 10
#define XY_PROBE_FEEDRATE (133*60)
#define Z_PROBE_FEEDRATE_FAST (4*60)
#define Z_PROBE_FEEDRATE_SLOW (Z_PROBE_FEEDRATE_FAST / 2)
#define Z_CLEARANCE_DEPLOY_PROBE   10 // (mm) Z Clearance for Deploy/Stow
#define Z_CLEARANCE_BETWEEN_PROBES  5 // (mm) Z Clearance between probe points
#define Z_CLEARANCE_MULTI_PROBE     5 // (mm) Z Clearance between multiple probes
#define Z_PROBE_LOW_POINT          -2 // (mm) Farthest distance below the trigger-point to go before stopping
#define Z_PROBE_OFFSET_RANGE_MIN -20
#define Z_PROBE_OFFSET_RANGE_MAX 20
#define X_ENABLE_ON 0
#define Y_ENABLE_ON 0
#define Z_ENABLE_ON 0
#define E_ENABLE_ON 0 // For all extruders
#define DISABLE_OTHER_EXTRUDERS   // Keep only the active extruder enabled
#define INVERT_X_DIR false
#define INVERT_Y_DIR true
#define INVERT_Z_DIR false
#define INVERT_E0_DIR false
#define INVERT_E1_DIR false
#define INVERT_E2_DIR false
#define INVERT_E3_DIR false
#define INVERT_E4_DIR false
#define INVERT_E5_DIR false
#define INVERT_E6_DIR false
#define INVERT_E7_DIR false
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

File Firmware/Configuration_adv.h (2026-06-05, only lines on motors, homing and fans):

#define E0_AUTO_FAN_PIN -1
#define E1_AUTO_FAN_PIN -1
#define E2_AUTO_FAN_PIN -1
#define E3_AUTO_FAN_PIN -1
#define E4_AUTO_FAN_PIN -1
#define E5_AUTO_FAN_PIN -1
#define E6_AUTO_FAN_PIN -1
#define E7_AUTO_FAN_PIN -1
#define CHAMBER_AUTO_FAN_PIN -1
#define COOLER_AUTO_FAN_PIN -1
#define HOMING_BUMP_MM      { 5, 5, 2 }       // (linear=mm, rotational=°) Backoff from endstops after first bump
#define HOMING_BUMP_DIVISOR { 2, 2, 4 }       // Re-Bump Speed Divisor (Divides the Homing Feedrate)
#define MICROSTEP_MODES { 16, 16, 16, 16, 16, 16 } // [1,2,4,8,16]
    #define X_CURRENT       800        // (mA) RMS current. Multiply by 1.414 for peak current.
    #define X_CURRENT_HOME  X_CURRENT  // (mA) RMS current for homing. (Typically lower than *_CURRENT.)
    #define X_MICROSTEPS     16        // 0..256
    #define Y_CURRENT       800
    #define Y_CURRENT_HOME  Y_CURRENT
    #define Y_MICROSTEPS     16
    #define Z_CURRENT       800
    #define Z_CURRENT_HOME  Z_CURRENT
    #define Z_MICROSTEPS     16
    #define E0_CURRENT      800
    #define E0_MICROSTEPS    16
  #define X_HYBRID_THRESHOLD     100  // [mm/s]
  #define X2_HYBRID_THRESHOLD    100
  #define Y_HYBRID_THRESHOLD     100
  #define Y2_HYBRID_THRESHOLD    100
  #define Z_HYBRID_THRESHOLD       3
  #define Z2_HYBRID_THRESHOLD      3
  #define Z3_HYBRID_THRESHOLD      3
  #define Z4_HYBRID_THRESHOLD      3
  #define I_HYBRID_THRESHOLD       3  // [linear=mm/s, rotational=°/s]
  #define J_HYBRID_THRESHOLD       3  // [linear=mm/s, rotational=°/s]
  #define K_HYBRID_THRESHOLD       3  // [linear=mm/s, rotational=°/s]
  #define U_HYBRID_THRESHOLD       3  // [mm/s]
  #define V_HYBRID_THRESHOLD       3
  #define W_HYBRID_THRESHOLD       3
  #define E0_HYBRID_THRESHOLD     30
  #define E1_HYBRID_THRESHOLD     30
  #define E2_HYBRID_THRESHOLD     30
  #define E3_HYBRID_THRESHOLD     30
  #define E4_HYBRID_THRESHOLD     30
  #define E5_HYBRID_THRESHOLD     30
  #define E6_HYBRID_THRESHOLD     30
  #define E7_HYBRID_THRESHOLD     30

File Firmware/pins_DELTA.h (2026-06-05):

/**
 * Marlin 3D Printer Firmware
 * Copyright (c) 2020 MarlinFirmware [https://github.com/MarlinFirmware/Marlin]
 *
 * Based on Sprinter and grbl.
 * Copyright (c) 2011 Camiel Gubbels / Erik van der Zalm
 *
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
 */
#pragma once

#include "env_validate.h"


#define BOARD_INFO_NAME "DELTA"

//
// Modified from pins file for: BigTreeTech BTT002 v1.0 (STM32F407VG)
//


//
// Limit Switches
//
#define X_STOP_PIN                          PD14
#define Y_STOP_PIN                          PD13
#define Z_STOP_PIN                          PD12  

//
// Z Probe must be this pin
//
#ifndef Z_MIN_PROBE_PIN
  #define Z_MIN_PROBE_PIN                   PD8
#endif



// 
// Steppers
//
#define X_STEP_PIN                          PD1
#define X_DIR_PIN                           PD0
#define X_ENABLE_PIN                        -1
#ifndef X_CS_PIN
  #define X_CS_PIN                          -1
#endif

#define Y_STEP_PIN                          PD3
#define Y_DIR_PIN                           PD2
#define Y_ENABLE_PIN                        -1
 #ifndef Y_CS_PIN
  #define Y_CS_PIN                          -1
#endif

#define Z_STEP_PIN                          PD5
#define Z_DIR_PIN                           PD4
#define Z_ENABLE_PIN                        -1
#ifndef Z_CS_PIN
  #define Z_CS_PIN                          -1
#endif

#define E0_STEP_PIN                         PD7
#define E0_DIR_PIN                          PD6
#define E0_ENABLE_PIN                       -1
#ifndef E0_CS_PIN
  #define E0_CS_PIN                         -1
#endif

//
// SPI pins for TMC2130 stepper drivers
//
#ifndef TMC_SPI_MOSI
  #define TMC_SPI_MOSI                      PB15
#endif
#ifndef TMC_SPI_MISO
  #define TMC_SPI_MISO                      PB14
#endif
#ifndef TMC_SPI_SCK
  #define TMC_SPI_SCK                       PB13
#endif

#if HAS_TMC_UART
  /**
   * TMC2208/TMC2209 stepper drivers
   *
   * Hardware serial communication ports.
   * If undefined software serial is used according to the pins below
   */
  //#define X_HARDWARE_SERIAL Serial1
  //#define X2_HARDWARE_SERIAL Serial1
  //#define Y_HARDWARE_SERIAL  Serial1
  //#define Y2_HARDWARE_SERIAL Serial1
  //#define Z_HARDWARE_SERIAL  Serial1
  //#define Z2_HARDWARE_SERIAL Serial1
  //#define E0_HARDWARE_SERIAL Serial1
  //#define E1_HARDWARE_SERIAL Serial1
  //#define E2_HARDWARE_SERIAL Serial1
  //#define E3_HARDWARE_SERIAL Serial1
  //#define E4_HARDWARE_SERIAL Serial1

  #define X_SERIAL_TX_PIN                   PA9
  #define Y_SERIAL_TX_PIN                   PA2
  #define Z_SERIAL_TX_PIN                   PB10
  #define E0_SERIAL_TX_PIN                  PA0

  // Reduce baud rate to improve software serial reliability
  #ifndef TMC_BAUD_RATE
    #define TMC_BAUD_RATE                  19200
  #endif

#endif // HAS_TMC_UART

//
// Temperature Sensors
//
#define TEMP_0_PIN                          PA5   // T0 <-> E0
#define TEMP_BED_PIN                        PA7   // T2 <-> Bed



//
// Heaters / Fans
//
#define HEATER_0_PIN                        PB0   // Heater0
#define HEATER_BED_PIN                      PB1   // Hotbed


#define FAN0_PIN                        PB6   // Fan0
 
#define FAN1_PIN                        PB7   // Fan1

#define FAN2_PIN                        PB8   // Fan2


/**
 *                ------                                    ------
 * (BEEPER) PE10 | 1  2 | PE11  (BTN_ENC)     (MISO)   PB14 | 1  2 | PB13 (SCK)
 * (LCD_EN) PE9  | 3  4 | PE8  (LCD_RS)      (BTN_EN1) PE12 | 3  4 | PB12 (SD_SS)
 * (LCD_D4) PE7  | 5  6 | PE6 (LCD_D5)       (BTN_EN2) PE13 | 5  6 | PB15 (MOSI)
 * (LCD_D6) PE5  | 7  8 | PE4 (LCD_D7)       (SD_DET)  PE15 | 7  8 | RESET PE14
 *           GND | 9 10 | 5V                            GND | 9 10 | NC
 *                ------                                    ------
 *                 EXP1                                      EXP2
 */
#define EXP1_01_PIN                         PE10
#define EXP1_02_PIN                         PE11
#define EXP1_03_PIN                         PE9
#define EXP1_04_PIN                         PE8
#define EXP1_05_PIN                         PE7
#define EXP1_06_PIN                         PE6
#define EXP1_07_PIN                         PE5
#define EXP1_08_PIN                         PE4

#define EXP2_01_PIN                         PB14
#define EXP2_02_PIN                         PB13
#define EXP2_03_PIN                         PE12
#define EXP2_04_PIN                         PB12
#define EXP2_05_PIN                         PE13
#define EXP2_06_PIN                         PB15
#define EXP2_07_PIN                         PE15
#define EXP2_08_PIN                         -1
#define EXP2_10_PIN                         -1

// HAL SPI1 pins
#define SD_SCK_PIN                   EXP2_02_PIN  // SPI1 SCLK
#define SD_SS_PIN                    EXP2_04_PIN  // SPI1 SSEL
#define SD_MISO_PIN                  EXP2_01_PIN  // SPI1 MISO
#define SD_MOSI_PIN                  EXP2_06_PIN  // SPI1 MOSI
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

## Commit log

2026-06-05 Rename Gerber files.zip to PCB/Gerber files.zip
2026-06-05 Rename Delta 3d printer.kicad_pcb to PCB/Delta 3d printer.kicad_pcb
    [Delta 3d printer.kicad_pcb]
2026-06-05 Rename Delta 3d printer.kicad_pro to PCB/Delta 3d printer.kicad_pro
2026-06-05 Rename Delta 3d printer.kicad_sch to PCB/Delta 3d printer.kicad_sch
    [Delta 3d printer.kicad_sch]
2026-06-05 Rename Base cover LCD_.step to CAD/Base cover LCD_.step
    [Base cover LCD_.step]
2026-06-05 Rename Base cover.step to CAD/Base cover.step
    [Base cover.step]
2026-06-05 Rename Bed support.step to CAD/Bed support.step
    [Bed support.step]
2026-06-05 Rename Bottom cover.step to CAD/Bottom cover.step
    [Bottom cover.step]
2026-06-05 Rename Drive arm.step to CAD/Drive arm.step
    [Drive arm.step]
2026-06-05 Rename LCD front cover.step to CAD/LCD front cover.step
    [LCD front cover.step]
2026-06-05 Rename Limit switch bracket.step to CAD/Limit switch bracket.step
    [Limit switch bracket.step]
2026-06-05 Rename New motor mount.step to CAD/New motor mount.step
    [New motor mount.step]
2026-06-05 Rename New top bracket.step to CAD/Top bracket.step
    [Top bracket.step]
2026-06-05 Rename New motor mount.step to Motor mount.step
    [Motor mount.step]
2026-06-05 Rename PSU Compartment.step to CAD/PSU Compartment.step
    [PSU Compartment.step]
2026-06-05 Rename PSU base cover.step to CAD/PSU base cover.step
    [PSU base cover.step]
2026-06-05 Rename bottom bracket.step to CAD/Bottom bracket.step
    [Bottom bracket.step]
2026-06-05 Rename New+assembly (1).stp to Assembly/Assembly.stp
    [Assembly.stp]
2026-06-06 Rename Delta printer BOM - Sheet1.csv to Delta printer BOM.csv
    [Delta printer BOM.csv]
2026-06-06 Rename Delta printer BOM.csv to BOM.csv
    [BOM.csv]
2026-06-07 Rename Delta printer BOM - Sheet1.csv to BOM.csv
    [BOM.csv]
2026-06-09 Rename New+assembly (2).stp to Assembly.stp
    [Assembly.stp]

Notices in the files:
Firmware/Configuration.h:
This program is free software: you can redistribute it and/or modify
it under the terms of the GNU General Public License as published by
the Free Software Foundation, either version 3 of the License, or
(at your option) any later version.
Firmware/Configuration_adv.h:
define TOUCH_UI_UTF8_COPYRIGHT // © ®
